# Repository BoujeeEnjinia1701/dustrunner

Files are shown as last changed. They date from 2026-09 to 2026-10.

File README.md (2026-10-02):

# DustRunner

     

**Area:** CleanTech · **TRL:** 3 of 9 (proof of concept on paper) · **Value-engineering target:** about $500 USD (estimated parts cost $573) · **Difficulty:** 4 of 5

Rail-free crawler robot that uses a rotating microfiber brush to dry-clean panel rows, clamps onto panel edges and docks to recharge.

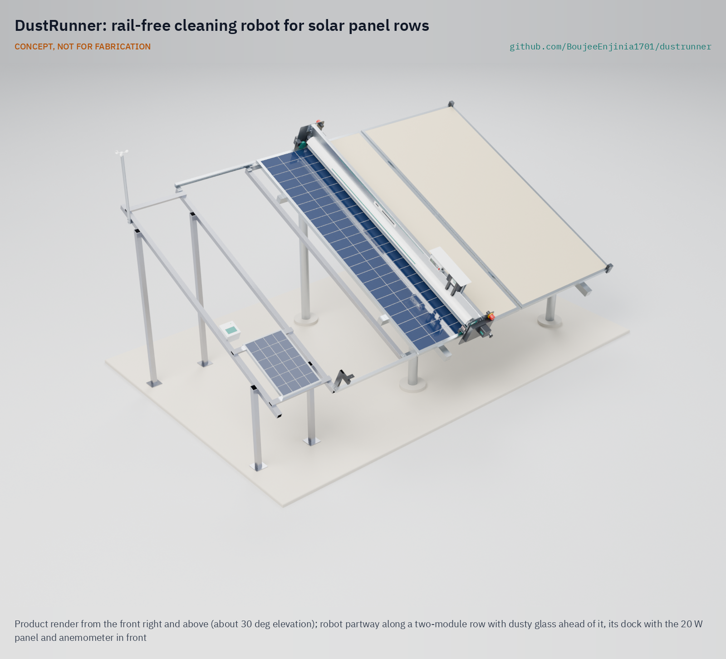
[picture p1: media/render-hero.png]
DustRunner: rail-free cleaning robot for solar panel rows, product render


[Exploded render](media/render-exploded.png) · [Detail render](media/render-detail.png) · [Interactive 3D model](media/viewer.html) · [Concept blueprint (PDF)](media/concept-blueprint.pdf) · [General arrangement DRN-DWG-001 (PDF)](cad/drawings/DRN-DWG-001.pdf) · [Sizing calculations](docs/04-calcs/01-sizing.md) · [Prototype build plan](docs/05-build-plan.md) · [Design decisions](docs/06-design-decisions.md) · [Review note](docs/REVIEW.md)

## Concept rationale

Soiling is a daily, gradual loss, so the answer is a small cleaning every day rather than a large one every month. Utility plants already do this with water-free robots bought as a service, but those machines are sized, priced and sold for rows hundreds of meters long. DustRunner scales the same idea down to one row of a small array: a full-width brush that rides on the module frames, so it needs no rails, never loads the glass and cannot fall between modules, and a dock that recharges it from a 20 W panel so it needs no wiring to the array.

The design is open and garage-buildable because the owners who need it most, farms with solar pumps, mini-grids and schools in dry regions, are far from robot vendors and service contracts. Aluminum tube, hobby gearmotors, a LiFePO4 pack and a microfiber sleeve can be bought, cut and repaired locally, and an open design can be adapted to other module lengths and table formats.

## Burning platform

Soiling cost at least 3 to 4 % of the world's solar electricity production in 2018, worth about 3 to 5 billion euros of lost revenue, with 4 to 7 % projected for 2023 as capacity grows fastest in dusty, sunny regions ([Ilse et al., Joule, 2019](https://www.cell.com/joule/fulltext/S2542-4351(19)30422-2)). The loss is steep where the sun is strongest: a 2026 study for Arar, Saudi Arabia, assumed monthly soiling losses of about 4 % in winter rising to 15 % in June and July ([Alharbi, *Energies*, 2026](https://www.mdpi.com/1996-1073/19/18/4373)).

Washing is the usual fix, and it spends water in the places that have least of it. Because each manual wash costs labor, the cost-optimal manual interval in the same study came out at about 60 days, and longer at low tariffs ([Alharbi, 2026](https://www.mdpi.com/1996-1073/19/18/4373)), so the array runs dirty for most of that time. A cheap daily dry pass changes that trade-off.

## Where it could be used

### By industry

| Industry | Use |
| --- | --- |
| Agriculture | Solar irrigation pumping arrays on farms, cleaned daily without trucking in water |
| Rural electrification | Mini-grid and community solar arrays at remote sites visited weekly or less |
| Commercial and light industrial | Ground-mounted arrays of 10 to 200 kW at warehouses, factories and depots |
| Education and health | School and clinic solar systems where no one is paid to clean panels |
| Water and telecoms utilities | Small arrays powering pumping stations, treatment plants and remote masts |
| Research and training | University test arrays and technical colleges comparing cleaning regimes |

### By country or region

| Country or region | Why it matters there |
| --- | --- |
| Saudi Arabia and the Gulf | Desert dust and scarce fresh water; a 2026 study for Arar assumed monthly soiling losses rising to 15 % in June and July ([Alharbi, 2026](https://www.mdpi.com/1996-1073/19/18/4373)) |
| Sahel and West Africa (for example Niger, Mali) | Harmattan dust from the Sahara can cut the output of decentralized solar and mini-grids by more than 50 % in the dry season, and Bamako needed about 21 cleanings a year to keep losses below 1 % ([Isaacs et al., *Applied Energy*, 2023](https://www.sciencedirect.com/science/article/abs/pii/S0306261923003574)) |
| India (Rajasthan, Gujarat) | More than 295,000 off-grid solar water pumps had been installed under the PM-KUSUM scheme by January 2024, about 59,700 of them in Rajasthan ([Press Information Bureau, 2024](https://www.pib.gov.in/PressReleaseIframePage.aspx?PRID=2004183&reg=3&lang=2)) |
| Chile (Atacama) | The Atacama has the highest long-term solar irradiance measured anywhere on Earth, with clouds present less than 5 % of the time in places, so arrays there are rarely washed by rain ([Molina, Falvey and Rondanelli, *Scientific Reports*, 2017](https://www.nature.com/articles/s41598-017-13761-x)) |
| Australia (inland) | A high-income market where ten deserts cover nearly 20 % of the country, the second driest continent ([Geoscience Australia](https://www.ga.gov.au/scientific-topics/national-location-information/landforms/deserts)) |

## What sparked the idea

The idea traces back to NASA's InSight lander on Mars, whose mission ended in December 2022 after dust gradually covered its solar panels and its batteries ran out of energy. With no cleaning mechanism on board, the team improvised: on windy days they sprinkled soil from the arm's scoop onto the panels so the falling grains would sweep some dust away and win back a little power ([NASA, "NASA Retires InSight Mars Lander Mission After Years of Science", 2022](https://www.nasa.gov/missions/insight/nasa-retires-insight-mars-lander-mission-after-years-of-science/)). The lesson carries back to Earth's deserts: a solar array without water depends on some dry, regular way of moving dust off the glass, and a small array needs one that costs no more than the energy it saves.

## Problem

Soiling cuts output of PV arrays in dusty regions by up to 15 to 25% a month in the dusty season, and water for washing is scarce.

## Concept

Rail-free crawler robot that uses a rotating microfiber brush to dry-clean panel rows, clamps onto panel edges and docks to recharge.

The robot spans one table from its lower to its upper module edge. End trucks ride on the module frames and hook under the frame lips, so no rails are needed along the row. A 2.2 m microfiber brush sweeps the glass dry once a day in the evening, and the robot parks off the glass in a clamp-on dock where a 20 W panel recharges its 12.8 V LiFePO4 pack and an anemometer checks the wind before each run. The TRL 3 calculations (DRN-CAL-001), run on the constructable design, give for a 40 m, 20 kWp row about 7.4 minutes and 7.7 Wh per cycle, a 15.9 kg robot and $573 in parts for robot, dock and anemometer, with a payback of about 3.2 years on rows of 60 m and 3 years from about 64 m. Six of fifteen requirements are met on paper, four are at risk (chiefly traction in wind, and the 60 m payback, which is over 3 years) and one falls short: the bearings, housings and fittings that make the design buildable put the parts USD 73 over the $500 value-engineering target. Amish restated the mass limit as 16.5 kg on 2026-10-02, with the wheel-load limits unchanged; the cost savings worth trying are in the design decisions register. Runs start only when the dock anemometer reads below 6 m/s and abort at 8 m/s (DRN-DDR-002). These are calculations, not test results.

Full design precis: [docs/02-concept.md](docs/02-concept.md)

## Key components

- Microfiber brush, 120 mm x 2.2 m, with brush motor and hood
- End trucks with belt-linked wheels and two drive gearmotors
- Edge-guide and hook rollers (the rail-free "clamp")
- 12.8 V 10 Ah LiFePO4 pack
- Controller (ESP32 class) and IR edge sensors
- Clamp-on dock with a 20 W PV panel, charger and anemometer; clamp-on end stops

The priced bill of materials is in [bom/bom.csv](bom/bom.csv); the parametric model is [cad/src/model.py](cad/src/model.py), with STEP files in `cad/step/`.

## Building the prototype

The [prototype build plan](docs/05-build-plan.md) shows, in pictures drawn from the model, how to make each of the 19 workshop-made components and fit them with the bought parts in 15 steps: the robot first, then the dock at the start of the row and the end stops at its far end. Making the design buildable added bearings, drive housings, roller brackets, dock brackets and clamps and a latch solenoid, recorded in [DRN-DDR-003](docs/decisions/0003-design-for-construction.md); they put the robot at about 15.9 kg and the parts at about $573. The work is sawing, drilling, tapping and folding aluminium, a little turning, and wiring bought modules at 12.8 V. Open decisions and the value-engineering notes are in the [design decisions register](docs/06-design-decisions.md).

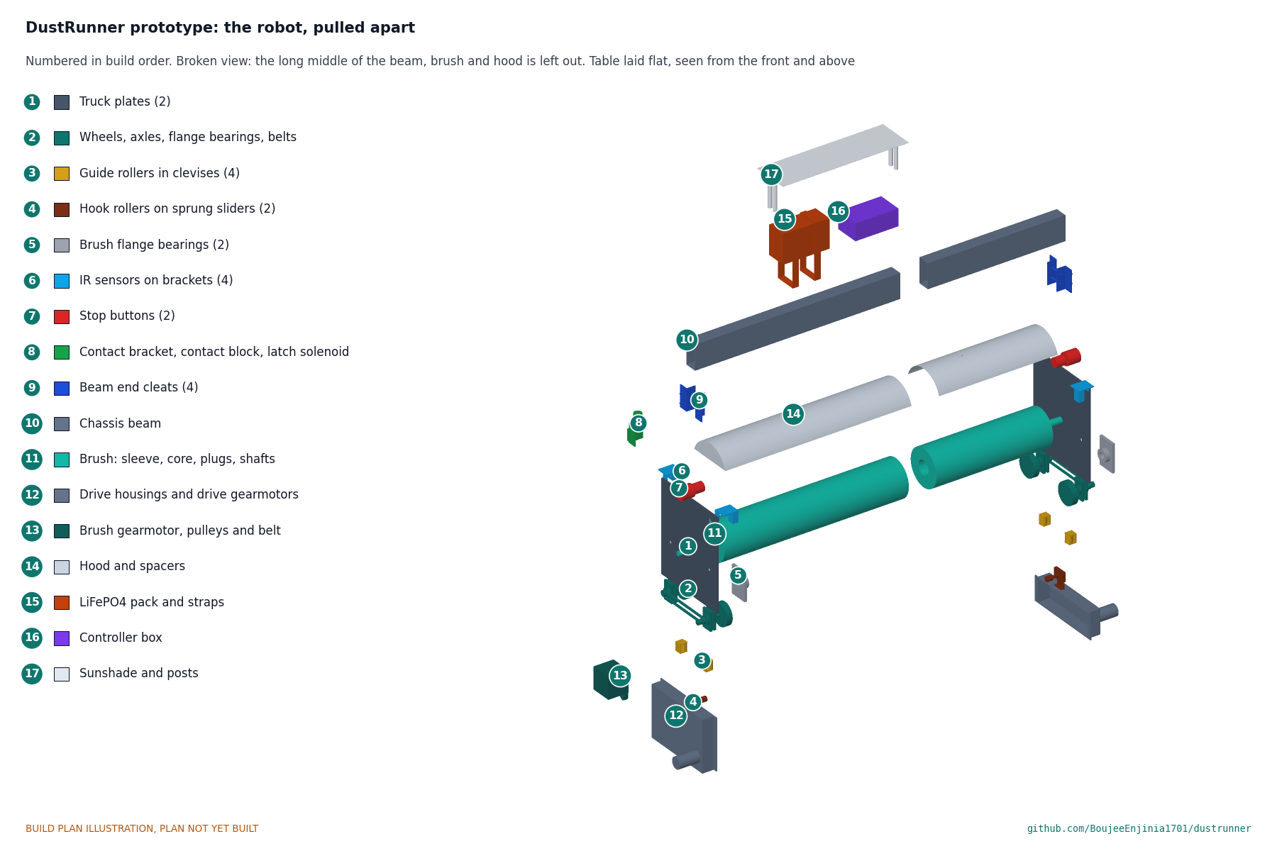
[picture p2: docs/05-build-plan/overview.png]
DustRunner robot, every component pulled apart and numbered in build order


## Safety

DustRunner is moving machinery with an unattended rotating brush and a lithium iron phosphate pack, and it works on live PV arrays at several hundred volts DC. The build plan's safety stops (Section 6) and the design precis's safety section apply to every build.

## Repository layout

| Folder | Contents |
| --- | --- |
| `docs/` | Problem, concept, requirements, calculations and design decisions |
| `cad/src/` | build123d Python source, the source of truth for all geometry |
| `cad/step/`, `cad/stl/` | Exported models for FreeCAD, other CAD tools and printing |
| `cad/drawings/` | 2D sketches and dimensioned drawings |
| `bom/` | Bill of materials |
| `electronics/` | KiCad schematics and PCB layouts |
| `firmware/` | Microcontroller code |
| `media/` | Renders, perspectives and photos |
| `build-log/` | Dated prototyping notes |

## Documentation

Controlled documents follow the portfolio [documentation standard](.kit/STANDARDS.md). Each carries a document ID (DRN-PRC-001 for the precis), a version and a revision history. Branded PDFs are built with `python .kit/render.py` and attached to GitHub Releases when a document is tagged, for example `DRN-PRC-001/v1.0`.

## Credits

Designed by Amish Chadha. See [CONTRIBUTORS.md](CONTRIBUTORS.md) for roles. To cite this design, use [CITATION.cff](CITATION.cff) (GitHub shows it as "Cite this repository").

AI assistance (Claude) was used to accelerate concept renders, prototype documentation and first-pass sizing calculations. Design direction and all decisions are Amish Chadha's, recorded in this repository's decision records (`docs/decisions/`).

## Licenses

- **Hardware** (CAD, drawings, BOM, electronics): [CERN-OHL-S v2](LICENSE)
- **Software** (firmware, scripts, notebooks): [MIT](LICENSE-SOFTWARE)

A project of the [Design Molecule](https://designmolecule.com) lab.

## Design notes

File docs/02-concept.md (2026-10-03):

---
doc_id: DRN-PRC-001
title: DustRunner design precis
project: DustRunner
doc_type: Design precis
version: "0.8"
status: Draft
date: '2026-10-02'
author: Amish Chadha
license: CERN-OHL-S-2.0
revisions:
- version: "0.1"
  date: '2026-09-24'
  author: Amish Chadha
  change: Initial scaffold
- version: "0.2"
  date: '2026-09-25'
  author: Amish Chadha
  change: Populate to TRL 2 (architecture, first-order numbers, traction, wind, economics, safety, media)
- version: "0.3"
  date: '2026-09-25'
  author: Amish Chadha
  change: TRL 3 update. Design choices decided per DRN-DDR-001; numbers replaced by DRN-CAL-001 (50 mm brush core, 70 N hook preload, 0.8 mm hood, dock anemometer); model, drawing DRN-DWG-001 and media refreshed
- version: "0.4"
  date: '2026-09-25'
  author: Amish Chadha
  change: Recommendations accepted by Amish (DDR-002). Start wind limit 6 m/s with abort at 8 m/s; row-entry wheel load accepted up to 75 N; budget kept at $500; numbers from DRN-CAL-001 v0.2
- version: "0.5"
  date: '2026-09-30'
  author: Amish Chadha
  change: Design made constructable (DRN-DDR-003); components and numbers from DRN-CAL-001 v0.3; build plan DRN-BLD-001 and design decisions register DRN-DEC-001 linked
- version: "0.6"
  date: '2026-10-01'
  author: Amish Chadha
  change: Budget treated as a value-engineering target
- version: "0.7"
  date: '2026-10-02'
  author: Amish Chadha
  change: 'Decisions of 2026-10-02 (DRN-DEC-001 v0.3): R10 met on paper at the restated 16.5 kg, R14 at risk, first candidate pilot site'
- version: "0.8"
  date: '2026-10-02'
  author: Amish Chadha
  change: 'Follow-ups carried out: calculation script re-run with the decided R10 and R14 status; numbers unchanged'
---

# DustRunner design precis

## Summary

DustRunner is a rail-free crawler robot that spans one PV table from its lower to its upper module edge, rides along the module frames on two end trucks that hook under the frame lips, and sweeps the glass dry with a 2.2 m rotating microfiber brush. It parks off the glass in a clamp-on dock at the start of the row, where a 20 W panel recharges its 12.8 V LiFePO4 pack and a cup anemometer tells it whether the wind allows a run. The TRL 3 calculations (DRN-CAL-001 v0.3), run on the constructable design of DRN-DDR-003, give for the 40 m, 20 kWp reference row about 7.4 minutes and 7.7 Wh per out-and-back cycle, a robot of about 15.9 kg and $573 in parts for robot, dock and anemometer. The bearings, housings, brackets and fittings that make the design buildable added about 2.1 kg and $73, so three requirements are now not met: the 15 kg mass limit of R10 (every wheel load still meets R10), the $500 budget of R13, and R14, with a payback of 3.2 years on a 60 m row (met from 63.5 m). Five are met and three are at risk: 5 mm frame steps (R4), traction in wind along the row (R9) and pack temperature (R11). A run starts only below 6 m/s at the dock anemometer and aborts above 8 m/s (DRN-DDR-002). How to resolve R10, R13 and R14 is open for Amish in the design decisions register ([06-design-decisions.md](06-design-decisions.md)); how to build the prototype is in the build plan ([05-build-plan.md](05-build-plan.md)).

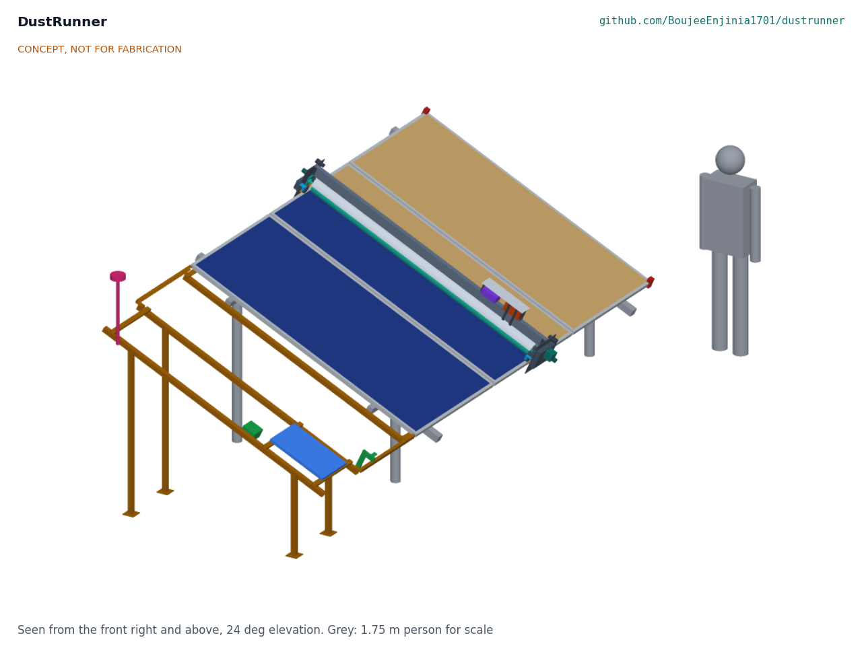
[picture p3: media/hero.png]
Hero render


*Figure 1. DustRunner partway along a three-module section of the reference table, moving away from its dock (brown, left, with the anemometer mast) toward the end stops (red). Glass behind the robot is clean; tan shows dust still to be removed. Grey figure: 1.75 m person for scale.*

## How it works

1. **Park and charge.** Between cycles the robot sits in the dock, a short pair of rails that continue the module frame profile past the end of the row. Parking off the glass means the robot never shades the array. A 20 W panel in the dock charges the pack through spring contacts; a third contact carries the anemometer signal.
2. **Start.** Once a day, in the evening after the array's output has dropped and before dew forms (DRN-DDR-001, D2), the controller checks pack charge, air humidity and the wind at the dock anemometer, sounds a short warning, then drives out of the dock. It starts only if the wind is below 6 m/s (DRN-DDR-002, N1).
3. **Travel.** Two end trucks carry the robot along the row. Each truck has two 70 mm polyurethane wheels on the top flange of the module frame, two guide rollers against the outer face of the frame and a hook roller under the frame's bottom flange, pushed up by a spring to 60 N. The trucks are the "clamp": they cannot lift off or slide down the slope, yet need no rail. A gearmotor with an encoder on each truck drives both of that truck's wheels through a toothed belt, and the controller keeps the two ends in step.
4. **Clean.** A 120 mm microfiber brush on a 50 mm aluminum core spans the slope and turns at about 150 rpm, pressed 4.5 mm into the glass plane at its bearings. A helical pattern on the brush conveys the loosened dust down the slope and off the lower edge. A hood over the brush limits dust thrown back onto clean glass.
5. **Stop and return.** IR sensors on each truck see the frame end; a clamp-on end stop at the far end is the mechanical backstop. The robot reverses the brush and cleans on the way back, then docks and latches. If the wind reported by the dock rises above 8 m/s during a run, the robot stops the brush and returns to the dock at once.

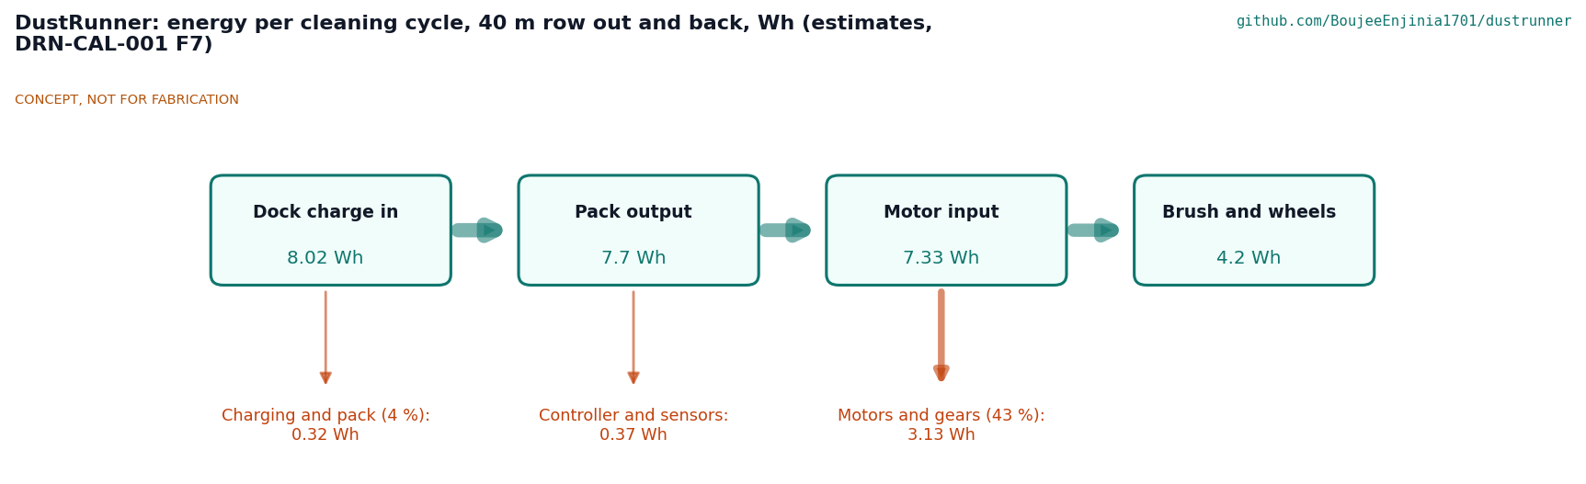
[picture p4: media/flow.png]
Energy flow


*Figure 2. Energy for one out-and-back cycle on the 40 m reference row, in Wh (DRN-CAL-001, F7). All values are estimates.*

## Main components

Numbers match the exploded view (Figure 3) and `bom/bom.csv`. Geometry is in `cad/src/model.py` and drawing DRN-DWG-001.

*Table 1. Main components.*

| # | Component | Choice | Notes |
| --- | --- | --- | --- |
| 1 | Chassis beam | 40 x 80 x 2 mm 6063 aluminum tube, 2,334 mm, bolted to each truck plate by two angle cleats | Cut to the module length for other tables |
| 2 | Microfiber brush | 120 mm diameter, 2,198 mm brushed length, on a 50 x 2 mm aluminum core | The 50 mm core keeps the interference at 3.4 to 4.4 mm along the brush |
| 3 | Brush hood | 0.8 mm aluminum sheet, 77 mm radius, with end guards and a sunshade over the pack | Also the finger guard at the brush ends |
| 4 | Brush motor and belt drive | 12 V DC gearmotor, about 60 W, toothed belt | Reversible; about 150 rpm at the brush; about 47 W in use |
| 5 | End trucks and wheels | 5 mm aluminum plates, 260 x 296 mm; two 70 x 18 mm polyurethane wheels each at 180 mm wheelbase on axles in flange bearings, belt-linked inside a drive housing that carries the motors | Wheels run on the frame top flange only |
| 6 | Drive gearmotors | Two 12 V 37 mm gearmotors with encoders, one per truck | Synchronized in firmware |
| 7 | Guide and hook rollers | 22 mm guide rollers in clevises on the frame face; 16 mm hook rollers on sprung sliders under the frame bottom flange, 60 N preload per truck | Keep the robot on the table in wind |
| 8 | Battery | LiFePO4, 12.8 V, 10 Ah (128 Wh) with BMS and temperature cut-offs | Under the sunshade |
| 9 | Controller | ESP32-class board, two drive channels, brush driver, current sensing, humidity and temperature sensor, IP65 box | Firmware is a sketch until TRL 4 |
| 10 | IR edge sensors | Four downward-looking reflective sensors, two per truck | Row-end and gap detection |
| 11 | Dock frame | Aluminum C-section rails continuing the module frame profile on brackets above three cross members, which stay clear of the hook roller path; two clamps to the first module's frame flange; ties; four legs | Clamp-on; no drilling |
| 12 | Dock PV panel | 20 W, about 530 x 350 mm, in the table plane | Charges the parked robot |
| 13 | Dock charger and contacts | LiFePO4 charge controller, three spring contacts on a post, latch tab; on the robot a contact block and a 12 V solenoid whose 6 mm pin drops into the tab | |
| 14 | End stops | Pair of three-piece clamps round the last module's frame edge, held by a clamp screw, with rubber buffers; low enough for the IR sensors to pass over | Mechanical backstop; the wheels meet the buffers |
| 16 | Dock anemometer | Cup anemometer with pulse output on a vertical mast clamped to the dock | Read before each start (DRN-DDR-001, D3) |

Item 15 (wiring, fuse, switches, stop buttons and fasteners) has no callout.

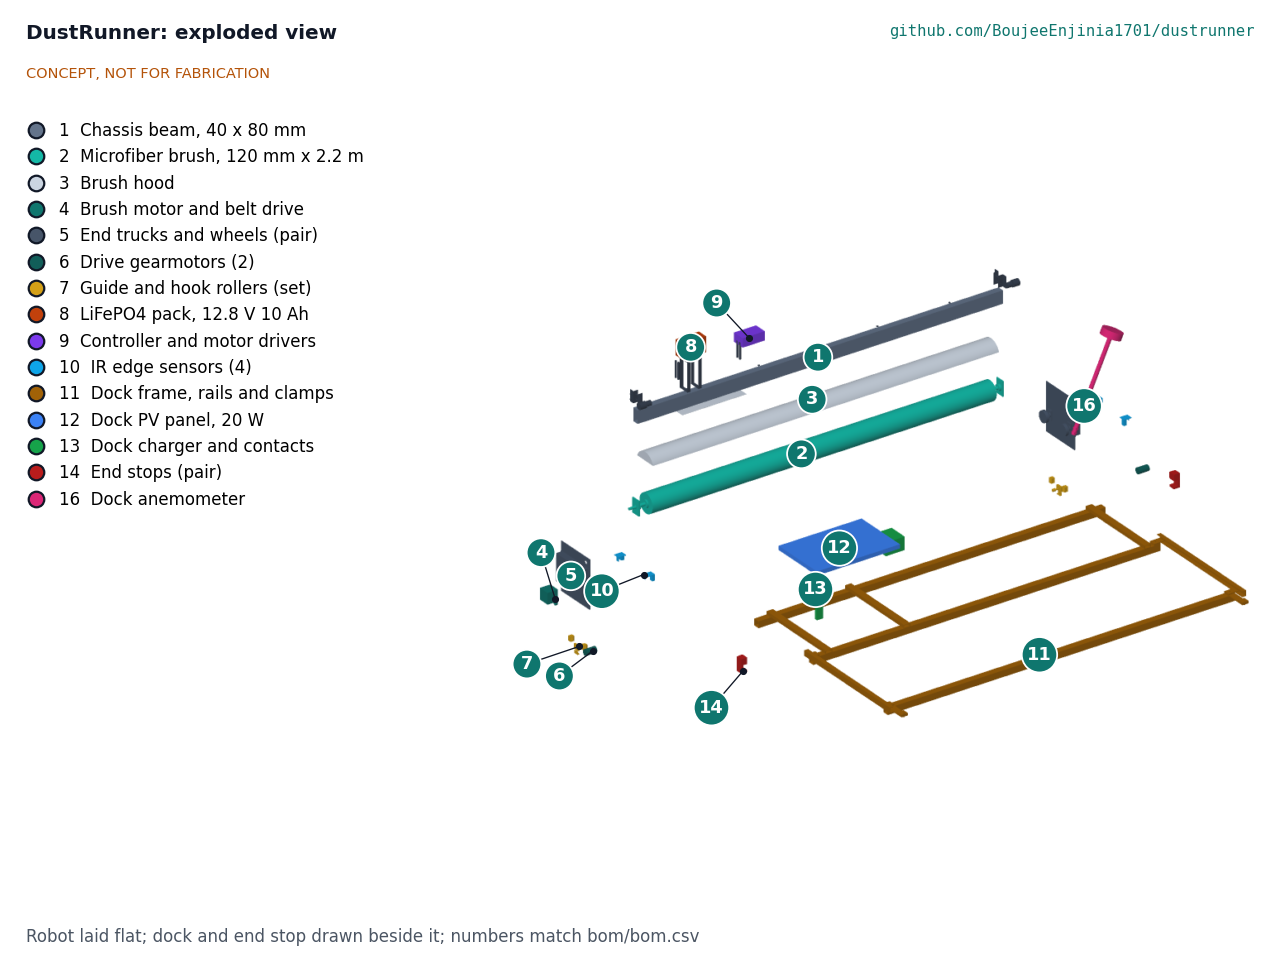
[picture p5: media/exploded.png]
Exploded view


*Figure 3. Exploded view with numbered callouts matching the BOM. The robot is laid flat in the table plane; the dock and end stops are drawn beside it. Upper-end twins of paired parts are shown without numbers.*

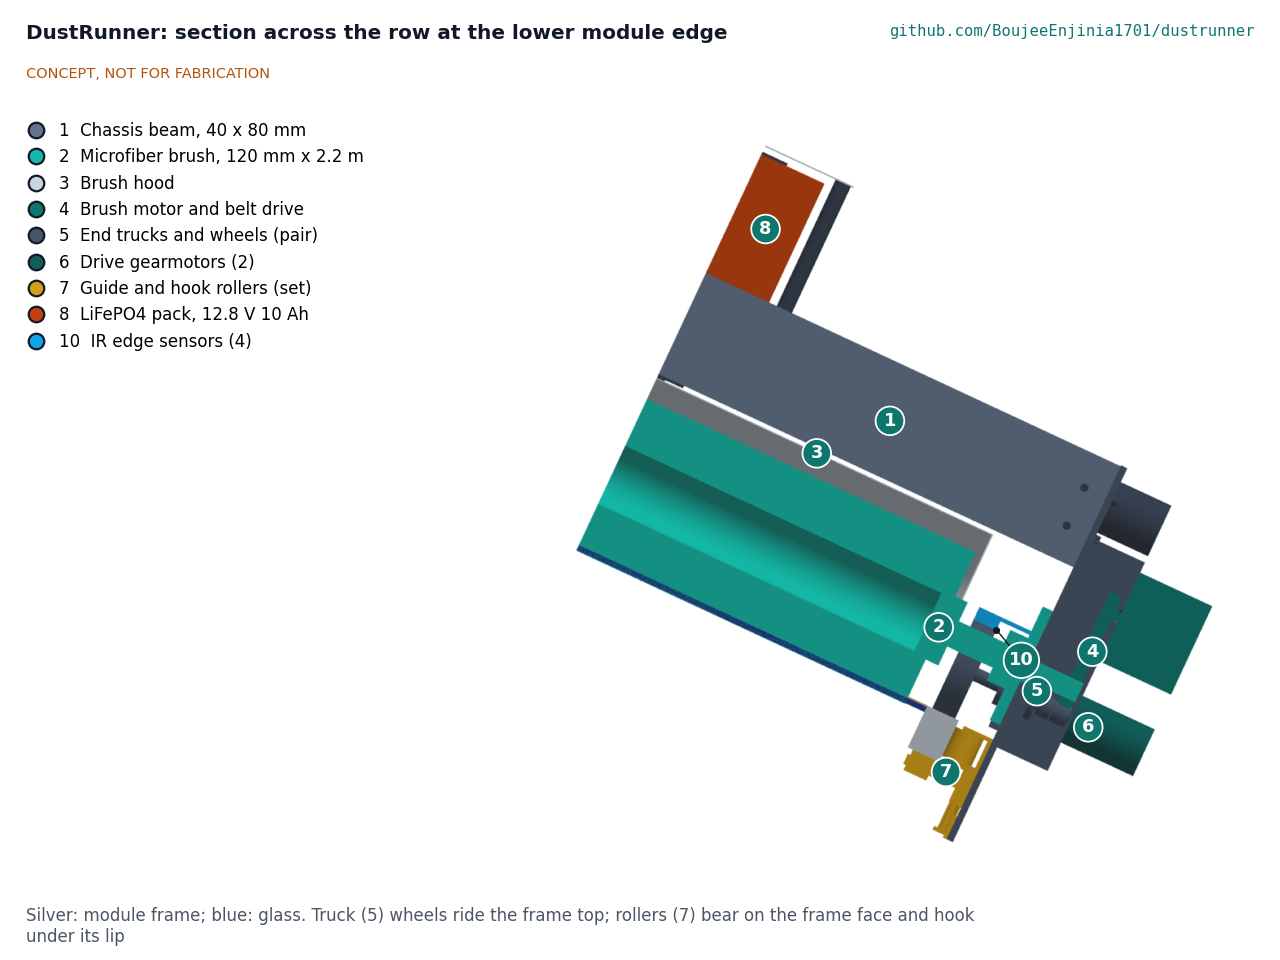
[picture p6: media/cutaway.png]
Cutaway


*Figure 4. Section across the row through the robot at the lower module edge, showing how the end truck wraps the frame.*

## Numbers at TRL 3

All values are from DRN-CAL-001 v0.2, which prints each from `docs/04-calcs/sizing.py`. They are first-principles estimates; the assumptions behind them (pile pressure, friction coefficients, frame flange width) are listed there and must be measured.

*Table 2. Key numbers.*

| Quantity | Value | Requirement |
| --- | --- | --- |
| Robot mass | 15.9 kg, including about 2.1 kg added for construction | R10 met on paper (16.5 kg, restated 2026-10-02); weighed at TRL 4 |
| Brush contact | About 67 N on the glass, 30 N drag, 28 W mechanical (13 to 50 W over the assumed ranges) | |
| Electrical power while cleaning | 67 W (brush 47 W, drives 17 W, electronics 3 W) | |
| Wheel load | 55 N brushing at 25°; 58 N at worst tilt; about 72 N for about a second at row entry | R10 met (75 N allowed for the transient, DRN-DDR-002) |
| Traction margin, friction 0.4 | 1.79 in still air; 1.30 at the 6 m/s start limit; 1.07 at the 8 m/s abort limit (0.98 and 0.81 at friction 0.3) | R9 at risk |
| 5 mm frame step | About 9 N extra push needed, about 14 N spare | R4 at risk |
| Parked at 35 m/s | 555 N along the row on a latch rated about 2.8 kN; 137 N net lift on the hook rollers | R9 parked case met |
| 40 m row, out and back | 7.4 min; 7.6 Wh from the pack | |
| 100 m row, out and back | 17.4 min; 19.6 Wh from the dock | R7 met |
| Autonomy | Three 100 m cycles and three days of standby use 67 of 102 Wh; 9 days with no sun on the 40 m row | R8 met |
| Dock harvest | 45 Wh/day at 3 sun hours; 82 Wh/day at 5.5 | R8 met |
| Coverage | 98.4 % of the glass on the 40 m row | R5 met |
| Stopping | Brush 0.13 s, robot 0.06 s after power is cut | R12 met |
| Parts cost | $573.00 (16 lines) | Over the value-engineering target by USD 73 (R13, target $500) |
| Payback, mid case | 3.2 years on a 60 m row (3 years from 63.5 m); 1.9 years on 100 m; 4.7 years on the 40 m reference row | R14 at risk (kept, not restated; 2026-10-02) |

The pack is cycled lightly (under 10 % of capacity a day on the reference row), which is kind to LiFePO4 cells in heat. The beam is not critical: with its load and a 250 N point load at mid-span it is stressed to about 17 MPa and deflects about 2.9 mm. Water saved is about 122 to 350 L per avoided wash of the reference row, about 1.5 to 4.2 m³ a year for monthly washing.

## Key design choices

Amish decided the design choices below on 2026-09-25 by approving the TRL 2 recommendations (DRN-DDR-001). Amish then accepted the recommendations raised by the TRL 3 calculations (DRN-DDR-002); they are listed after the first set.

- **One robot per row, spanning the full slope** (D1). A full-width robot needs no steering on the glass and cannot fall between modules. The concept is limited to tables whose short edges are free of clamps, as stated in R4.
- **Ride on the frame edges, not on the glass** (D1, D10). Wheels on the frame keep weight off the glass and coating. The first supported format is 1P portrait tables of 2,278 mm modules.
- **Rail-free, with a short dock and clamp-on end stops** (D11). The dock and stops are the only added hardware and clamp on without drilling. The mechanical end stops stay as the independent backstop to the IR sensors.
- **Dry microfiber brush, no water and no airflow** (D12). Airflow is added only if tests show that dust is re-deposited.
- **Charging at the dock from a 20 W panel** (D4), not from a panel on the robot.
- **Both wheels driven on each truck, with preloaded hook rollers** (D5). DRN-CAL-001 sets the preload by a 60 N wheel-load rule: 60 N per truck for the constructable design.
- **Evening cleaning, gated by the humidity sensor** (D2). While on the glass the robot shades a strip along one module for a few seconds, which costs 1 to 2 kWh a year.
- **Anemometer at the dock** (D3), read through the dock contacts before each start.
- **LiFePO4 at 12.8 V, 10 Ah** (D6). A SwapCell pack is not used: at about 468 Wh and 48 V it is far larger than DustRunner needs.
- **Reference row and payback target** (D7, D8). The 40 m reference row is kept; R14 applies to rows of 60 m or more.
- **Budget** (D9). `budget_usd` stays at $500 for robot, dock and anemometer as a hypothetical value-engineering target, not a limit. The priced BOM of the constructable design is $573, USD 73 over the target; savings worth trying are in DRN-DEC-001.
- **Start and abort wind limits** (DRN-DDR-002, N1). A run starts only below 6 m/s at the dock anemometer and aborts above 8 m/s. This is a firmware rule; it lifts the traction margin at the start of a run from 1.07 to 1.30 at friction 0.4 and will be revisited once friction is measured.
- **Row-entry wheel load** (DRN-DDR-002, N2). R10 allows up to 75 N per wheel for the second or so as the lead wheels enter the first module, subject to the module maker's frame guidance; no landing strip is added.
- **No cost contingency yet** (DRN-DDR-002, N3). `budget_usd` stays at $500 as the value-engineering target and the estimate stays indicative until quotes exist. Getting quotes is purchasing, which is TRL 4 work and on hold.

## Safety

> **Safety:** DustRunner is moving machinery with a rotating brush, a lithium iron phosphate battery, and it works on an energized PV array that can carry several hundred volts DC, on hot glass, up to about 1.6 m above the ground.

- **Rotating brush and pinch points.** The brush, belts and wheels can catch fingers, hair and clothing. The hood covers the brush ends; each truck has an emergency stop button; the brush stops when a truck lifts off the frame. The brush coasts to rest in about 0.13 s once power is cut (DRN-CAL-001, H1). Nobody should reach under the hood while the robot is powered.
- **Unexpected start.** The robot runs on a timer with nobody present. It must carry a clear warning label, start only after a short audible warning, and have a lockout switch at the dock.
- **Falling robot.** A 15.9 kg robot leaving the row end could injure someone below. Two independent stops (IR sensing and the mechanical end stop) and the hook rollers address this (R9). The end stop and dock latch hold with factors above 4 on paper, but traction in wind is marginal, so runs start only below 6 m/s and abort above 8 m/s (DRN-DDR-002; DRN-CAL-001, C4, C13, D1 to D4).
- **PV array electrical hazard.** Strings carry DC voltages that can be lethal and cannot be switched off in daylight. Nothing on the robot may touch cables, connectors or junction boxes; installation and maintenance follow the array owner's electrical safety rules. Damaged module glass exposes live parts.
- **Battery.** LiFePO4 is less prone to thermal runaway than other lithium-ion chemistries but can still vent and burn if crushed, shorted or overcharged. Use a pack with a BMS, fuse the pack output, block charging below 0 °C and above about 45 °C, and keep the pack shaded and ventilated (R11 is at risk on pack temperature).
- **Hot surfaces.** Module glass and frames can reach about 75 °C. Wear gloves when installing or servicing in daylight.
- **Module warranty.** Abrasive cleaning, or a cleaning tool the maker has not cleared, can void the module warranty. Check the maker's cleaning guidance and ask the maker to clear the robot before use (see DRN-PRB-001).

## Open questions

- [ ] Brush pile pressure, drag power and cleaning effectiveness on real dust, dry and after dew (R2).
- [ ] Long-term abrasion of anti-reflective coatings by daily microfiber contact (R3).
- [ ] Friction coefficient of polyurethane on dusty frames (R9); the traction margin in wind depends on it.
- [ ] Visible frame flange width of target modules; the wheel tread needs about 21 mm (R4).
- [ ] Pack temperature when parked in the sun, and the charging window it allows (R11).
- [ ] Module makers' positions on frame loading, including the 72 N row-entry transient, and on robotic dry cleaning (R10).
- [ ] How dust conveyed off the lower edge builds up at the lower frame lip over time.
- [ ] Pilot site and co-design partner (DRN-DDR-001, O1). Decided 2026-10-02: a university or national lab outdoor PV test site in a dusty climate; first candidate to approach Arizona State University's Photovoltaic Reliability Laboratory in Mesa.

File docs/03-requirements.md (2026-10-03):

---
doc_id: DRN-REQ-001
title: DustRunner requirements
project: DustRunner
doc_type: Requirements
version: "0.8"
status: Draft
date: '2026-10-02'
author: Amish Chadha
license: CERN-OHL-S-2.0
revisions:
- version: "0.1"
  date: '2026-09-24'
  author: Amish Chadha
  change: Initial scaffold
- version: "0.2"
  date: '2026-09-25'
  author: Amish Chadha
  change: First measurable requirements for TRL 2, with a reference row and status against the concept
- version: "0.3"
  date: '2026-09-25'
  author: Amish Chadha
  change: Apply DRN-DDR-001 (R14 restated for rows of 60 m or more; R13 covers the anemometer; reference row and table format kept); status from DRN-CAL-001
- version: "0.4"
  date: '2026-09-25'
  author: Amish Chadha
  change: Recommendations accepted by Amish (DDR-002). R9 restated with a 6 m/s start limit and 8 m/s abort limit; R10 allows 75 N for the row-entry transient; status from DRN-CAL-001 v0.2
- version: "0.5"
  date: '2026-09-30'
  author: Amish Chadha
  change: Status from DRN-CAL-001 v0.3 for the constructable design (DRN-DDR-003); R10 (mass), R13 and R14 not met. No target changed
- version: "0.6"
  date: '2026-10-01'
  author: Amish Chadha
  change: Budget treated as a value-engineering target
- version: "0.7"
  date: '2026-10-02'
  author: Amish Chadha
  change: R10 mass limit restated as 16.5 kg (wheel loads unchanged) and R14 kept and marked at risk, as decided by Amish on 2026-10-02
- version: "0.8"
  date: '2026-10-02'
  author: Amish Chadha
  change: 'Status from DRN-CAL-001 v0.6 (script re-run; printed counts agree with the decided counts); no target changed'
---

# DustRunner requirements

These requirements are checked by calculation in DRN-CAL-001 v0.6, for the constructable design of DRN-DDR-003. On paper, six are met, four are at risk, one falls short of its target and four cannot be verified at TRL 3. The parts added to make the design buildable moved R10, R13 and R14 off their targets; on 2026-10-02 Amish decided to restate R10's mass limit as 16.5 kg, keeping the wheel-load limits (the robot weighs 15.9 kg and is weighed at TRL 4), and to keep R14 and treat it as at risk until quotes (3.2 years on a 60 m row; met from 63.5 m). R13 falls short (estimated parts cost $573, USD 73 over the value-engineering target of $500); the cost savings worth trying are in the value engineering section of the design decisions register (DRN-DEC-001). The others at risk are R4 (5 mm frame steps and frame flange width), R9 (traction in wind along the row, margin 1.30 at the 6 m/s start limit but 0.98 if friction is only 0.3) and R11 (pack temperature while charging in the sun). R2, R3, R6 and R15 need tests or trials. Targets are still proposals for review, not validated with users or a pilot site, except where DRN-DDR-001 or DRN-DDR-002 records Amish's decision.

The **reference row** used throughout, kept by DRN-DDR-001 (D7), is one fixed-tilt table, one module high in portrait (1P), with 35 modules of 2,278 x 1,134 mm and about 580 W each: about 40 m long, about 90 m² of glass and about 20 kWp, tilted 25°, with the lower glass edge about 0.6 m above the ground. The first supported table format is 1P portrait with 2,278 mm modules (DRN-DDR-001, D10).

*Table 1. Requirements and status at TRL 3.*

| ID | Requirement | Target | Status (DRN-CAL-001) | Verification (TRL 3 or later) |
| --- | --- | --- | --- | --- |
| R1 | Water-free cleaning | No water or liquid used in normal operation | Met by design | Design review |
| R2 | Cleaning effectiveness on dry dust | Daily dry pass keeps the average soiling loss at 1.5 % or less when the site soiling rate is 0.3 to 0.5 % per day | **Not verifiable at TRL 3**; depends on dust type and dew. R14 on the 60 m row would need a residual below 1.3 % | Later soiling-station comparison |
| R3 | Glass and coating safety | Only microfiber touches the glass; brush interference 3 to 5 mm along the whole brush; no hard bristles, grit traps or metal within 10 mm of the glass; complies with the module maker's cleaning guidance | **Not verifiable at TRL 3**; geometry met (3.5 to 4.4 mm with a 50 mm core; nothing else within 10 mm); abrasion over years unknown | Maker guidance review; later abrasion test on sample glass |
| R4 | Fit the reference table | 1P portrait modules 2,278 mm long with 30 to 35 mm frames; short (top and bottom) edges free of clamps; tilt 10 to 35°; gaps between modules up to 25 mm; frame height steps up to 5 mm | **At risk**: 25 mm gaps pass; a 5 mm step needs about 9 N against about 12 N spare traction; the wheel tread needs a visible frame flange of about 21 mm or more | Survey of target tables and frame profiles |
| R5 | Coverage | 95 % or more of the glass area brushed per pass | Met: 98.4 % on the 40 m row | Model check |
| R6 | Rail-free installation | No rails along the row; only a dock at one end and clamp-on end stops at the other; no drilling of modules or structure; installed by two people in 60 min or less | **Not verifiable at TRL 3**; rail-free and clamp-on by design; time unverified | Installation trial |
| R7 | Cycle time | A 100 m row cleaned out and back in 20 min or less | Met: 17.4 min | Calculation |
| R8 | Energy autonomy | Three daily cycles on a 100 m row with no sun; recharged from the dock panel in one day at 3 peak sun hours | Met: 68 of 102 Wh usable; 45 Wh harvested against 23 Wh a day | Energy calculation |
| R9 | Stay on the row | Two independent means stop the robot at each row end; hook rollers keep it on the table in operating wind; a run starts only when the dock anemometer reads below 6 m/s and aborts to the dock above 8 m/s (DRN-DDR-002, N1); robot parked and latched in the dock survives 35 m/s | **At risk**: parked, latch and end stops hold with factors over 4; traction margin 1.30 at the 6 m/s start limit and 1.07 at the 8 m/s abort limit at friction 0.4, but 0.98 and 0.81 at friction 0.3 | Wind load calculation; later friction measurement |
| R10 | Load on the modules | Robot mass 16.5 kg or less (restated from 15 kg by Amish, 2026-10-02, DRN-DEC-001); each wheel load 60 N or less in steady running and 75 N or less for the brief transient as the lead wheels enter the first module (DRN-DDR-002, N2), subject to the module maker's frame loading guidance; carried on the frame only; no load on the glass except brush contact | **Met on paper**: 15.9 kg with the parts added for construction, to be weighed at TRL 4. Wheel loads met: 59 N per wheel brushing at worst tilt with 60 N hook preload; about 73 N for about a second at row entry | Mass estimate; module maker's guidance |
| R11 | Environment | Electronics IP65; operates at 0 to 50 °C ambient on glass up to 75 °C; UV-stable plastics; dust-sealed bearings | **At risk**: the parked pack may exceed its 45 °C charging limit in the sun; a sunshade is added | Datasheets and design review; later thermal check |
| R12 | Safe to be near | Emergency stop button on each end truck; brush and drives stop within 2 s of a stop command or of a truck lifting off the frame; brush ends guarded by the hood; nothing on the robot can reach PV cables, connectors or junction boxes | Met on paper: brush stops in 0.13 s, robot in 0.07 s; belt guards and a stop button in each truck plate | Design review; later bench test |
| R13 | Affordable | Robot, dock and anemometer for one row, parts at or below the value-engineering target of $500 (`budget_usd`, a hypothetical control target) | **Over the value-engineering target by USD 73**: $573.00 indicative after the parts added for construction (DRN-DDR-003); the target stays at $500 (DRN-DDR-002, N3); savings to try are in DRN-DEC-001 | Priced BOM (`bom/bom.csv`) |
| R14 | Pays for itself | Value of the recovered energy covers the parts cost in 3 years or less on rows of 60 m or more, mid case (0.3 % per day soiling, monthly manual wash as baseline, $0.10/kWh) | **At risk** (kept, not restated; Amish, 2026-10-02): 3.2 years on a 60 m row at $573, revisited when real quotes exist; met on rows of 63.5 m or more; 1.9 years on a 100 m row (4.7 years on the 40 m reference row, which is below the scope of R14) | Energy yield calculation |
| R15 | Serviceable | Microfiber sleeve replaced in 15 min or less without taking the robot off the row; motors, bearings, wheels and battery are standard catalog parts | **Not verifiable at TRL 3**; catalog parts by design | Later service trial |

## Assumptions

- Specific yield about 5.5 kWh per kWp per day for a clean array at a sunny desert site (estimate).
- Soiling rate 0.3 % per day (mid case) and 0.49 % per day (high case, as measured at QEERI in Qatar; see DRN-PRB-001).
- Baseline practice is a manual wash every 30 days. Longer manual intervals, or no cleaning at all, make DustRunner's case stronger.
- Electricity or displaced diesel valued at $0.10/kWh. Diesel-displacing mini-grids are often higher.
- 20 W dock panel, 75 % derating for heat, dust, wiring and a simple charge controller.
- Friction coefficients, brush pile pressure and the visible frame flange width are assumptions listed in DRN-CAL-001, Table 1, and must be measured.

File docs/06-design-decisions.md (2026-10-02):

---
doc_id: DRN-DEC-001
title: DustRunner design decisions register
project: DustRunner
doc_type: Design decisions register
version: "0.3"
status: Draft
date: '2026-10-02'
author: Amish Chadha
license: CERN-OHL-S-2.0
revisions:
  - version: "0.1"
    date: '2026-09-30'
    author: Amish Chadha
    change: Register opened with the build plan; open decisions from DRN-DDR-001 to 003 and the review note
  - version: "0.2"
    date: '2026-10-01'
    author: Amish Chadha
    change: Budget treated as a value-engineering target
  - version: "0.3"
    date: '2026-10-02'
    author: Amish Chadha
    change: Amish approved the recommendations for open items 1 to 7 on 2026-10-02 (DRN-DDR-003 accepted, R10 mass restated as 16.5 kg, R14 kept and at risk, robot-side latch solenoid, ASU Photovoltaic Reliability Laboratory as first candidate pilot, appearance items, re-render); moved to decisions made
---

# DustRunner design decisions register

Every design decision still to be made, and every decision made, in one place. Each decision is argued in full in its decision record under `docs/decisions/`; this register is the index Amish works from. The build plan (`docs/05-build-plan.md`, DRN-BLD-001) describes the design as it stands and does not list open decisions.

## Open decisions

None. All open decisions were decided on 2026-10-02.

## To confirm when parts are bought

| # | What to confirm | Why it matters | Source |
| --- | --- | --- | --- |
| 1 | The target modules' frame: top flange at least 21 mm wide (25 mm assumed), frame 33 mm deep, and room on top of the long-side bottom flange for the 6 mm clamp jaw | Wheel tread, hook roller, dock rail profile and frame clamp all depend on it | DRN-CAL-001 [C12]; DRN-DDR-003, P12 |
| 2 | The flange bearings' bolt spacing and height (10 mm and 20 mm bores) | They set the bearing bolt holes and the clearances to the sensor brackets (4 mm) and clevises | DRN-DDR-003, P3, P5 |
| 3 | The gearmotors' face hole patterns and shaft sizes | They set the housing holes and the 6 to 10 mm coupling | DRN-DDR-003, P4 |
| 4 | A compression spring giving 60 N at 20 mm, about 9 mm across | Sets the hook preload | DRN-CAL-001 [C0] |
| 5 | The solenoid's pull and stroke against the pin's return spring, at 12 V for about 1 s | The robot must lift its own latch pin | DRN-DDR-003, P9 |
| 6 | The charge controller's LiFePO4 profile (14.4 V) and the pack BMS's 0 °C and 45 °C charge cut-offs | Battery safety (R11) | DRN-PRC-001, Safety |
| 7 | The module maker's cleaning and frame-load guidance (60 N steady, 75 N at row entry) | R3 and R10 | DRN-DDR-002, N2 |
| 8 | The real masses of the bought parts | The 15.9 kg estimate and the preload rule | DRN-CAL-001 [A2], [A4] |

## Value engineering

Value-engineering target: USD 500 (a hypothetical control target, not a limit). Estimated cost of the constructable design: USD 573 (USD 73 over the target). Main cost drivers and savings worth trying:

- The USD 73 over the target is the parts added to make the design buildable (DRN-DDR-003): flange bearings, drive housings, couplings, roller clevises and sliders, dock brackets, clamps, ties and foot plates, the latch solenoid and beam cleats. The largest single lines are the LiFePO4 pack (USD 45), the beam (USD 30) and the dock panel (USD 22).
- Savings worth trying at quotes: cheaper flange bearings, a lighter dock, and 4 mm or pocketed truck plates (which also save about 1 kg; R10's mass limit was restated as 16.5 kg on 2026-10-02, so this is now a saving, not a fix).
- Every price is indicative; quotes are TRL 4 work and on hold (DRN-DDR-002, N3).

## Decisions made

| Date | Decision | Decided by | Record |
| --- | --- | --- | --- |
| 2026-09-25 | TRL 2 review items D1 to D12: full-width robot on 1P frames, evening cleaning gated by humidity, dock anemometer, 20 W dock charging, both wheels driven with preloaded hook rollers, 12.8 V LiFePO4 pack, 40 m reference row, R14 restated for rows of 60 m or more, budget $500, 1P portrait 2,278 mm modules first, mechanical end stops kept, dry microfiber without airflow | Amish: "proceed with all of your recommendations across all batches. Make sure we don't proceed to TRL 4 on any of them." | DRN-DDR-001 |
| 2026-09-25 | Start a run only below 6 m/s and abort at 8 m/s (N1); R10 allows 75 N per wheel for the row-entry transient (N2); keep `budget_usd` at $500 as the value-engineering target and look at contingency on quotes (N3) | Amish: "i accept all your recommendations, go with them across all repos." | DRN-DDR-002 |
| 2026-09-26 | DustRunner chosen for the first batch of product renders | Amish | `docs/REVIEW.md`, session 2026-09-26 |
| 2026-09-30 | Write the illustrated build plan and make the design physically buildable while drawing it; keep open decisions out of the build plan, in this register | Amish: "If you are realising that the design cannot be built as per concept - fix the design assumptions to match and be physically feasible as you draw the illustrations." The changes made under this instruction were accepted on 2026-10-02 (below). | DRN-DDR-003; DRN-BLD-001 |
| 2026-10-02 | Design for construction accepted: the changes P1 to P16 that make the design buildable (guide roller clevises and 28 mm plate gap, sprung hook sliders, flange bearings, drive housings, beam cleats, latch solenoid, dock rail brackets, frame clamps, vertical legs and mast, three-piece end stops), as drawn | Amish: "i approve your recommendations for all 555 open decisions." | DRN-DDR-003, P1 to P16 |
| 2026-10-02 | Robot mass: option (c), R10's mass limit restated as 16.5 kg now, with the 60 N and 75 N wheel-load limits unchanged; the robot is weighed at TRL 4 | Amish: "i approve your recommendations for all 555 open decisions." | DRN-DDR-003, A2; DRN-CAL-001 [A3], [A4] |
| 2026-10-02 | Payback: option (b), R14 kept at 3 years on rows of 60 m or more and marked at risk rather than restated; revisited when real quotes exist | Amish: "i approve your recommendations for all 555 open decisions." | DRN-DDR-003, A3; DRN-CAL-001 [I4], [I9] |
| 2026-10-02 | Latch release: option (a), the robot-side 12 V solenoid lifts its own pin, as drawn | Amish: "i approve your recommendations for all 555 open decisions." | DRN-DDR-003, A4 |
| 2026-10-02 | Pilot site and co-design partner: a university or national lab outdoor PV test site in a dusty climate; first candidate to approach Arizona State University's Photovoltaic Reliability Laboratory in Mesa | Amish: "i approve your recommendations for all 555 open decisions." | DRN-DDR-001 and 002, O1 |
| 2026-10-02 | Product appearance model deviations 1 to 6 accepted for renders, except that the dock contact bracket and bearing flanges (item 5) are taken from the constructable design, not as appearance-only parts | Amish: "i approve your recommendations for all 555 open decisions." | `docs/REVIEW.md`, session 2026-09-26 |
| 2026-10-02 | Renders: option (a), update `cad/src/product_model.py` to the constructable design and re-render the photoreal renders, card and social preview on Amish's Mac | Amish: "i approve your recommendations for all 555 open decisions." | DRN-DDR-003, Consequences |

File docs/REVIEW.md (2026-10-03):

# Review note: DustRunner

## Session 2026-09-25: /populate to a strong TRL 2 (overnight batch run)

### What was done

- `docs/01-problem.md` (DRN-PRB-001 v0.2): problem with cited soiling and water figures, users and operating context, prior work (Ecoppia, NOMADD, SolarCleano, an academic prototype) with links, constraints including module warranty and live-array hazards, out of scope, open questions. There was no co-design checklist to keep.
- `docs/03-requirements.md` (DRN-REQ-001 v0.2): 15 measurable requirements (R1 to R15) against a defined 40 m, 20 kWp reference row, with a status column and assumptions.
- `docs/02-concept.md` (DRN-PRC-001 v0.2): how it works, numbered components, mass, power and energy per cycle, autonomy, traction, wind, recovered energy and payback, cost, design choices, safety, open questions.
- `cad/src/concept_media.py`: massing model of a three-module section of the reference table (frames, glass, dust film, purlins, posts), the robot (beam, brush, hood, motors, end trucks, rollers, battery, controller, sensors), the clamp-on dock with its 20 W panel, and the end stops. Every robot and dock part carries a BOM number.
- `media/`: hero with a 1.75 m person, blueprint sheet (PNG, PDF, SVG), `model.glb` and `viewer.html`, exploded view with callouts 1 to 14, cutaway (section across the row at the lower module edge) and an energy flow diagram per cleaning cycle with estimated values. The exploded view and cutaway are rendered by the script with the kit's renderer so the robot is readable at a useful scale; temporary `_views` folders are removed.
- `bom/bom.csv`: 15 lines with indicative prices, numbered to match the exploded view; `bom/bom-notes.md` updated.
- `README.md`: hero image, links line, concept paragraph and key components updated.
- `docs/pdf/`: branded PDFs of the three controlled documents.

### Key results (estimates, to be checked at TRL 3)

| Quantity | Estimate | Requirement |
| --- | --- | --- |
| Robot mass | about 12 kg; about 52 N per wheel on the frames with hook preload | R10 met on paper |
| Power while cleaning | about 70 W (brush 50 W, drives 16 W, electronics 3 W) | |
| 40 m row, out and back | about 7 min, about 8 Wh from the dock | |
| 100 m row, out and back | about 17 min, about 20 Wh | R7 met |
| Autonomy | about 102 Wh usable; about 5 days on a 100 m row with no sun | R8 met |
| Dock panel harvest | about 82 Wh/day at 5.5 sun hours, 45 Wh/day at 3 | R8 met |
| Coverage | about 98 % of the glass across the slope | R5 met |
| Traction | about 83 N available against about 39 N needed (both wheels driven, 50 N hook preload per truck, friction 0.4 assumed) | Margin about 2, unverified |
| Wind while cleaning | stop above 8 m/s; parked at 35 m/s about 650 N along the row and 170 N net lift | R9 unverified |
| Recovered energy, mid case | about 1,220 kWh a year, about $120 a year | |
| Payback | about 4.0 years mid case; about 2.0 years at 0.49 %/day; about 1.6 years on a 100 m row | **R14 not met** in the mid case |
| Parts cost | about $485 for robot and dock | R13 met, about 3 % margin |

Requirements not met or not shown:

- **R14 (payback within 3 years) not met** in the mid case on the 40 m reference row: about 4 years.
- **R2 (cleaning effectiveness) not shown:** the 1.5 % residual loss with daily dry cleaning is an assumption; dew-cemented dust may not come off dry.
- **R3 (glass and coating safety) not shown:** long-term abrasion from daily microfiber contact is unknown, and some module makers require approval of motorized cleaning tools.
- **R9 (wind) unverified:** the operating wind limit needs a wind input that is not in the BOM.
- **R13 margin is thin:** an anemometer would bring the cost to about $500.

### Proposed, awaiting Amish

Status update: items 1 to 8 and 10 were decided by Amish, 2026-09-25: go with recommendation (DRN-DDR-001, D1 to D12). Item 9 has no recommendation and stays proposed, awaiting Amish.

1. **Scope: one full-width robot per row, riding on the frames of 1P portrait tables.** Options: (a) as proposed; (b) a smaller robot that moves on the glass; (c) add a transfer cart between rows. Recommendation: (a). This limits fit to tables whose short module edges are free of clamps.
2. **Cleaning time.** Options: night (as Ecoppia does), evening before dew forms, or dawn. Recommendation: evening, gated by the humidity sensor.
3. **Wind input.** Options: (a) anemometer at the dock (about $15, cost about $500); (b) a weather feed over the network; (c) a fixed wind rule from motor current. Recommendation: (a).
4. **Charging at the dock rather than a panel on the robot.** Recommendation: dock panel, 20 W.
5. **Traction: both wheels driven on each truck and spring-preloaded hook rollers.** Recommendation: yes, pending friction measurement.
6. **12.8 V LiFePO4, 10 Ah.** A SwapCell pack is not proposed because DustRunner needs about a quarter of its energy at a quarter of its voltage. Recommendation: LiFePO4.
7. **Reference row for requirements and payback.** 40 m and 20 kWp is proposed. A 100 m reference would meet R14; that choice changes how the pitch is judged, so it is Amish's.
8. **R14 target.** Options: keep 3 years and accept that the reference row does not meet it; relax it to 5 years; or restate it per row length. Recommendation: restate it as "3 years or less on rows of 60 m or more".
9. **Pilot site and partner** (solar pumping farm, mini-grid operator or university test array).
10. **Budget.** Parts cost is within `budget_usd` ($500); no change proposed. `project.yaml` is unchanged, including `pitch` and `problem`: the "15 to 25 %" figure matches arrays left a month or more in the dusty season (QEERI about 13 % a month, Arar 11 to 18 % a month in summer), and DRN-PRB-001 now states that context. A more precise wording ("up to 15 to 25 % a month in the dusty season") is suggested for Amish to consider.

### Safety concerns

- Rotating brush, belts and wheels on an unattended machine that starts on a timer: guards, emergency stops on both trucks, an audible start warning and a lockout at the dock.
- A 12 kg robot falling from up to 1.6 m if it leaves the row end or is lifted by wind: two independent end stops and hook rollers; wind loads unverified.
- Live PV strings at several hundred volts DC that cannot be switched off in daylight: the robot must never touch cables, connectors or junction boxes; damaged glass exposes live parts.
- LiFePO4 pack: BMS, fused output, no charging below 0 °C, shaded and ventilated.
- Hot glass and frames up to about 75 °C during installation and service.
- Module warranty risk from abrasive cleaning or cleaning tools the maker has not cleared.

### Problems and notes

- The kit's default scale figure stands in front of the table's lower edge, where it hid the robot's lower end and the dock, so the script places the 1.75 m person itself as a context part standing on the ground beyond the far end of the row.
- The legacy `cad/src/model.py` placeholder is untouched (TRL 3 work).
- Suggestion, not done: a soiling-station measurement at the pilot site before any build would answer R2 and R14 at low cost.

### Recommended next step

Review this note and the media, then decide items 1, 3, 7 and 8. If approved, run `/advance-trl3` to check the brush power, traction, wind and frame-load estimates by calculation and produce the parametric model and drawing sheet.

## Session 2026-09-25: TRL 3

Amish approved all TRL 2 recommendations on 2026-09-25 ("proceed with all of your recommendations across all batches. Make sure we don't proceed to TRL 4 on any of them."). This session advanced DustRunner to TRL 3 and stopped there.

### What was done

- `docs/decisions/0001-trl2-review-decisions.md` (DRN-DDR-001 v0.1): decisions D1 to D12 recorded as "Decided by Amish, 2026-09-25: go with recommendation"; O1 (pilot partner) left open.
- `docs/01-problem.md`, `docs/02-concept.md`, `docs/03-requirements.md` revised to v0.3: problem line reworded, design choices no longer "proposed", R14 restated for rows of 60 m or more, R13 now covers the anemometer, every number replaced by DRN-CAL-001 values.
- `docs/04-calcs/01-sizing.md` (DRN-CAL-001 v0.1) and `docs/04-calcs/sizing.py`: mass, brush contact and core deflection, wheel loads, traction, frame steps, wind, beam, energy, coverage, stopping, cost and payback, with a status for every requirement. The script imports the model and reads the BOM and budget.
- `cad/src/model.py`: parametric build123d model (robot, dock, end stops, reference module) exporting `cad/step/dustrunner-{robot,dock,end-stop,assembly}.step` and `cad/stl/dustrunner-{robot,dock,end-stop}.stl`.
- `cad/src/sheets.py` and `cad/drawings/DRN-DWG-001.{svg,pdf,png}`: general arrangement at Rev P1 (top and front views at 1:20, section A-A at 1:5, isometric, interface notes), marked "CONCEPT, NOT FOR FABRICATION" and "PRELIMINARY, NOT FOR FABRICATION". The concept sheet stays DRN-DWG-010, so DWG-001 was free.
- `bom/bom.csv`: 16 lines, all priced with a supplier type; item 16 (dock anemometer) added. `bom/bom-notes.md` updated.
- `cad/src/concept_media.py` now builds the robot, dock and end stops from `model.py`; all media re-rendered and checked (hero, blueprint, exploded with callout 16, cutaway, flow, GLB and viewer). No `_views` folders remain.
- `project.yaml`: `trl: 3`, `trl_target: 3`, `trl_evidence` lists the docs, DDR, CAL note and script, model, STEP files, drawing and BOM; problem line reworded. `README.md` matches.

### Requirements at TRL 3 (DRN-CAL-001, Table 8)

Six met, five at risk, none not met, four not verifiable at TRL 3.

| Status | Requirements |
| --- | --- |
| Not met | None |
| At risk | R4 (5 mm frame step: 9 N needed, 14 N spare; tread needs a frame flange of about 21 mm or more); R9 (traction margin 1.10 in an 8 m/s wind along the row at friction 0.4, 0.82 at friction 0.3); R10 (13.8 kg and 58 N per wheel brushing, but about 72 N for about a second at row entry); R11 (pack may exceed its 45 °C charge limit in the sun); R13 ($500.00 against $500, no margin) |
| Not verifiable at TRL 3 | R2 (cleaning effectiveness), R3 (abrasion; the geometry is met), R6 (installation time), R15 (sleeve change time) |
| Met | R1, R5 (98.4 %), R7 (17.4 min), R8 (67 of 102 Wh), R12 (0.13 s), R14 (2.8 years on a 60 m row) |

Key numbers: robot 13.8 kg; 67 W while cleaning; 7.4 min and 7.6 Wh per cycle on the 40 m row; 17.4 min on a 100 m row; parked at 35 m/s, 555 N along the row and 137 N net lift, held with factors over 4; payback 4.1 years on the 40 m row, 2.8 years on 60 m, 3.5 years on 60 m if sleeves are replaced every year.

Changes forced by the calculations: the brush core grows from 40 to 50 mm (a 40 mm core lets the interference fall to 2.8 mm mid-span, outside R3); hook preload set at 70 N per truck (highest value keeping brushing wheel loads at 60 N or less); hood thinned to 0.8 mm; a sunshade added over the pack. Mass rose from about 12 kg to 13.8 kg.

### Decisions recorded

D1 to D12 in DRN-DDR-001: full-width robot on 1P frames; evening cleaning gated by humidity; anemometer at the dock; 20 W dock charging; both wheels driven with preloaded hook rollers; 12.8 V LiFePO4, no SwapCell; 40 m reference row kept; R14 restated for rows of 60 m or more; budget kept at $500 with the problem line reworded; 1P portrait 2,278 mm modules first; mechanical end stops kept; dry microfiber without airflow. The SwapCell interface v0.3 items do not apply because DustRunner uses its own pack.

### Proposed, awaiting Amish

1. **Pilot site and co-design partner (O1).** No recommendation; to be picked per area later. Still proposed, awaiting Amish.
2. **Start wind limit (new, from C4 and C7).** Options: (a) keep 8 m/s and accept a traction margin of about 1.1; (b) start a run only below 6 m/s at the dock anemometer and keep 8 m/s as the abort limit; (c) raise the hook preload, which breaks the 60 N wheel-load target. Recommendation: (b), revisited once friction is measured. This changes the R9 target, so it is Amish's. **Decided by Amish, 2026-09-25: go with recommendation** (DRN-DDR-002, N1).
3. **Row-entry wheel load (new, from C2).** Options: (a) restate R10 to allow about 75 N for the brief row-entry transient, subject to the module maker's frame guidance; (b) add a glass-height landing strip at the dock end so the brush is loaded on entry (small cost, over budget); (c) lower the preload to about 55 N and accept less traction. Recommendation: (a). **Decided by Amish, 2026-09-25: go with recommendation** (DRN-DDR-002, N2).
4. **Cost contingency (new, from I1).** The BOM uses the whole $500. Options: keep $500 and treat R13 as at risk until quotes exist; or raise `budget_usd` to about $550 to hold a 10 % contingency. Recommendation: keep $500 for now; decide on quotes. `budget_usd` is unchanged. **Decided by Amish, 2026-09-25: go with recommendation** (DRN-DDR-002, N3).

### Safety concerns

- Unattended rotating brush, belts and wheels that start on a timer: guards, a stop button on each truck, an audible start warning and a lockout at the dock. Stopping time is well inside 2 s on paper.
- A 13.8 kg robot falling from up to 1.6 m: end stops and the dock latch hold with factors over 4, but traction in wind along the row is marginal; the start wind limit (item 2) matters for safety as well as function.
- Live PV strings at several hundred volts DC: nothing on the robot may touch cables, connectors or junction boxes; damaged glass exposes live parts.
- LiFePO4 pack parked in the sun: BMS with low- and high-temperature charge cut-offs, fused output, sunshade and ventilation (R11 at risk).
- Hot glass and frames up to about 75 °C; module warranty risk from cleaning tools the maker has not cleared.

### Other notes

- No existing TRL 4 material was found (the `build-log/` folder holds only its README and was not touched).
- The review note listed no unchecked citations, so none were re-verified in this session.
- Friction coefficients, brush pile pressure and the visible frame flange width are assumptions; they drive R4, R9 and the brush power.

### Recommended next step

Decide items 2 to 4 above and name a pilot partner when ready. **TRL 4 is on hold by Amish's instruction**, and no TRL 4 work was started. For reference only, TRL 4 would need: measured friction of polyurethane on dusty frames and measured brush pile pressure and drag; a survey of target module frame profiles; a lab test article of one end truck on a frame section, and of the brush on sample glass (effectiveness and abrasion); a pack temperature check in the dock; a test report (TST, `environment: lab`) and build log entries.

## Session 2026-09-25: recommendations accepted

Amish wrote on 2026-09-25: "i accept all your recommendations, go with them across all repos." Every open item with a recommendation is now "Decided by Amish, 2026-09-25: go with recommendation", recorded in `docs/decisions/0002-recommendations-accepted.md` (DRN-DDR-002 v0.1).

### Decisions applied and what changed

| # | Decision | Before | After |
| --- | --- | --- | --- |
| N1 | Start a run only below 6 m/s at the dock anemometer; abort at 8 m/s | Operate below 8 m/s; traction margin 1.10 at start (friction 0.4) | Start below 6 m/s: margin 1.33 at friction 0.4, 1.00 at 0.3 [C13]; abort at 8 m/s: 1.10 and 0.82. R9 still at risk |
| N2 | R10 allows about 75 N per wheel for the row-entry transient | 72 N against a 60 N limit: R10 at risk | 72 N against 75 N (transient), 58 N against 60 N (steady): R10 met |
| N3 | Keep `budget_usd` at $500; decide contingency on quotes | $500, BOM $500.00 | Unchanged: $500, BOM $500.00; R13 still at risk |

Files changed: DRN-REQ-001 v0.3 to v0.4 (R9 and R10 restated, R13 note); DRN-PRC-001 v0.3 to v0.4 (start and abort rule, design choices, key numbers); DRN-CAL-001 v0.1 to v0.2 and `sizing.py` (new [C13], restated R9 and R10 checks); DRN-DDR-002 v0.1 (new); `project.yaml` (DDR-002 added to `trl_evidence`; `budget_usd`, pitch and problem unchanged); `README.md` (status line and the new write-up sections). Geometry, BOM and prices are unchanged, so DRN-DWG-001 stays at Rev P1; the STEP, STL, drawing, media and PDFs were regenerated.

### Requirement status now (DRN-CAL-001 v0.2)

| Status | Requirements |
| --- | --- |
| Not met | None |
| At risk | R4 (5 mm frame step and flange width); R9 (traction margin 1.33 at the 6 m/s start limit, 1.00 at friction 0.3); R11 (pack charge temperature in the sun); R13 ($500.00 against $500) |
| Not verifiable at TRL 3 | R2, R3, R6, R15 |
| Met | R1, R5, R7, R8, R10, R12, R14 |

Counts: 7 met (was 6), 4 at risk (was 5), 0 not met, 4 not verifiable.

### Still awaiting Amish

- O1: pilot site and co-design partner (no recommendation was made).

### Cross-repo actions

None. DustRunner uses its own 12.8 V pack (DRN-DDR-001, D6) and no shared module.

### TRL 4

TRL 4 remains on hold by Amish's instruction. The parts of N1 and N3 that need TRL 4 work (measuring wheel friction on dusty frames, writing firmware beyond a sketch, requesting supplier quotes) are decided but on hold. `trl: 3` and `trl_target: 3` are unchanged.

## Session 2026-09-26: sources strengthened

- "By country or region" in `README.md`: five of six rows had no citation. Each row now carries a verified primary or peer-reviewed source, and the text was trimmed to what the source supports:
  - Sahel and West Africa: no source, now [Isaacs et al., *Applied Energy*, 2023](https://www.sciencedirect.com/science/article/abs/pii/S0306261923003574) (Harmattan soiling losses above 50 % for decentralized solar; about 21 cleanings a year in Bamako).
  - India (Rajasthan, Gujarat): no source, now [Press Information Bureau, 8 February 2024](https://www.pib.gov.in/PressReleaseIframePage.aspx?PRID=2004183&reg=3&lang=2) (PM-KUSUM off-grid solar pumps installed, national and Rajasthan figures).
  - Chile (Atacama): no source, now [Molina, Falvey and Rondanelli, *Scientific Reports*, 2017](https://www.nature.com/articles/s41598-017-13761-x) (highest long-term irradiance on Earth, very low cloud occurrence).
  - Australia (inland): no source, now [Geoscience Australia, deserts](https://www.ga.gov.au/scientific-topics/national-location-information/landforms/deserts); the unsupported claim about remote farms and service distances was removed.
  - US Southwest: removed, because no credible source was verified within this session's search allowance. Australia, Chile and Saudi Arabia remain as high-income examples.
- Arar figures (Alharbi, *Energies*, 2026): on checking the paper, the adopted monthly losses are about 4 % in winter rising to 15 % in June and July; 11 to 18 % is a literature range quoted for comparison. The README and DRN-PRB-001 (v0.4) now quote the adopted values, and the 60-day manual interval is stated as the base-case optimum, longer at low tariffs.
- Kept and verified: NASA InSight retirement release (What sparked the idea), Alharbi 2026. Ilse et al., *Joule*, 2019 is peer-reviewed and kept; it could not be re-fetched in this session.
- Not changed (outside this session's scope): DRN-PRB-001 still cites PV Tech (trade press) alone for the QEERI figures and Polywater (vendor) alone for water per module; both should get primary sources at the next revision.
- The "Qatar 11 to 18 %" wording in item 10 of the TRL 2 session above predates this correction.
- No budget change.

## Session 2026-09-26: product appearance model and photoreal renders

Amish chose this repo for the first batch of product renders on 2026-09-26.

### What was done

- `cad/src/product_model.py` (new): a product appearance model for photoreal renders. `product_parts()` returns every part with its colour, material, BOM line, group and exploded-view offset; `TITLE` and `RENDER_VIEWS` define three views: `hero` (robot partway along a two-module row with its dock and anemometer in front), `exploded` (robot, dock and end stops) and `detail` (the lower end truck clamped on a section of the module frame). It adds:
  - Robot: anodized beam with fillets, an accent stripe and a name plate; white powder-coated hood with rolled edges, hangers and an accent band; microfiber sleeve (fabric) on its core ends, stub shafts and bearing flanges; sunshade frame on four posts; strapped LiFePO4 pack with a label; IP65 controller box with a lid parting line, a clear side window showing the board, a shielded module and a lit status light, a main switch and cable glands.
  - End trucks: graphite plates with corner fillets, lightening holes, bolts and a badge; polyurethane tyres on metal hubs; wheel belt guards; drive gearmotors split into gearbox, can and encoder cap; guide rollers on clevis tabs; hook arms with rollers and preload springs; IR sensors with lenses; copper charge contacts; a red emergency stop on a yellow base on each truck (the two stop buttons of BOM item 15). The lower truck also carries the brush gearmotor housing (with cooling slots) and the brush belt cover.
  - Dock: C-section rails, cross members and posts, painted clamps with bolts, legs with feet, a framed 20 W panel with cells, a charger box with a lit charge light, spring contacts with the latch pin on a contact post, and a three-cup anemometer on its mast. End stops get rubber buffers and clamp bolts.
  - Context (not in the BOM): two reference modules (frames, backsheet, cells), a dust film ahead of the robot (illustrative), purlins, rafters, posts with concrete footings and a compact gravel ground patch.
- `README.md`: the hero image now points to `media/render-hero.png`, and the links line starts with the exploded render. The render files will be produced by the orchestrator.
- Self-check previews (matplotlib, clear parts left out) were reviewed for all three views; they are scratch files, not repo media.

### Differences from model.py (each Proposed, awaiting Amish)

1. Coordinates. model.py builds everything in local table coordinates (glass plane). The product model builds each part in those coordinates and then places it with the same tilt transform as `cad/src/concept_media.py` (Z up, ground at Z = 0), because the renderer needs a ground plane. Recommendation: accept; no dimension changes.
2. Scene layout. The robot is shown at u = 560 mm, partway along the first of two modules, not parked in the dock as in `assembly()`. Recommendation: accept, since it shows the brush on the glass and the dock together.
3. Exploded view. The dock is drawn 300 mm nearer the robot along the row and the end stops 900 mm nearer, so the exploded view stays compact; the dock legs are left out of it. Recommendation: accept (render layout only).
4. Groups. The lower end truck, the brush drive and a short section of the module frame are in the `internal` group so the `detail` view can frame the edge clamp; the upper truck, its mirror image, is in `shell`. Recommendation: accept.
5. Small appearance additions not in model.py: a bracket and foot that tie the dock contact block to the rail (model.py shows the block alone), the sunshade posts and cross bars that seat it on the beam, bearing flanges on the truck plates, hood hangers, pack straps, and rubber buffers on the end stops. These imply small hardware covered by BOM items 3, 11, 13, 14 and 15; no BOM line or cost changes. Recommendation: accept as appearance only, and confirm the dock contact bracket at the next design revision.
6. Materials and colours. Wheel tyres are shown in the kit accent (#0F766E) and the hood and sunshade in white powder coat; model.py sets no finishes. Recommendation: accept, or choose a different tyre colour.

### Status

This is an appearance model only: no tolerances, no fabrication detail, no change to PARAMS, the BOM, the calculations or the drawing. `trl` stays 3 and TRL 4 remains on hold.

## Session 2026-09-27: kit 1.5.0 and image quality

- Kit 1.5.0 synced: STANDARDS v1.5 (sections 12 to 15: product renders, storefront images and image quality, public release, authorship and signing), `.kit/cards.py`, `.kit/image_qc.py`, `.kit/release_gate.py`, issue templates, and the `/render-product` and `/release` commands. `CLAUDE.md` now matches `.kit/CLAUDE.md`.
- Every `media/render-*.png` recaptioned from its original render with the new layout: the title, concept label and repository sit in a band above the render and the view note in a band below it, each line wrapped to the image width, so no text overlaps other text or the render or runs off the image. `media/card.png` and `media/social-preview.png` regenerated with the same rules.
- `python .kit/image_qc.py` and `python .kit/release_gate.py` pass. trl stays 3.

## Session 2026-09-30: prototype build plan and design for construction (kit 1.7.0)

Kit 1.7.0 installed (`.kit/`, `.claude/commands/`, `CLAUDE.md`). Amish's instructions of 2026-09-30: write the illustrated build plan in the approved format, "fix the design assumptions to match and be physically feasible as you draw the illustrations", and keep outstanding decisions out of the build plan in a separate register.

### What was done

- `cad/src/model.py` rebuilt to a constructable level of detail: `build_components()` returns every robot, dock and end-stop part; `python cad/src/model.py --check` runs 123 constructability checks (contacts, clearances, robot on the module, parked in the dock and at the end stop, hook roller path); all 123 pass. STEP and STL re-exported.
- `docs/decisions/0003-design-for-construction.md` (DRN-DDR-003 v0.1, Draft): every change, its reason, the knock-on changes and four items proposed, awaiting Amish.
- `docs/05-build-plan.md` (DRN-BLD-001 v0.1): 19 made components, bought parts, wiring, 15 assembly steps, first checks, safety stops, tools.
- `docs/06-design-decisions.md` (DRN-DEC-001 v0.1): 8 open decisions (7 after the 2026-10-01 budget wording pass), 8 items to confirm when parts are bought, decisions made.
- `cad/src/build_plan_media.py`: overview pictures (robot and dock), making sketches `cad/drawings/DRN-DWG-101` to `119`, 11 joint close-ups, 15 step pictures and a wiring diagram in `docs/05-build-plan/`.
- `docs/04-calcs/sizing.py` and DRN-CAL-001 v0.3 re-run for the constructable design (new [A4], [C0], [I9]); DRN-REQ-001 v0.5 and DRN-PRC-001 v0.5 updated; `bom/bom.csv` and `bom/bom-notes.md` repriced; `cad/src/sheets.py` and DRN-DWG-001 Rev P3; concept media regenerated (`cad/src/concept_media.py`); `project.yaml` (`design_state: constructable`, new evidence); README links line, "Building the prototype" and a short "Safety" section.

### Design changes made for construction (DRN-DDR-003)

1. Truck plate gap 28 mm (was 22): each guide roller now turns on an M8 bolt in a folded clevis, 6 mm off the plate (it used to fill the gap and rub the plate).
2. Hook roller on an 8 mm axle cantilevered from a 10 mm slider that runs on shoulder bolts and is pushed up by a spring on a seat bracket (the concept had a rigid arm, no axle, no spring); plates 24 mm taller (296 mm).
3. Each wheel axle in two flange bearings, one each side of the plate (stub axles could not carry the outboard belt).
4. Folded drive housings on the outer faces guard the belts and carry the gearmotors (which floated); shaft couplings; wheel and brush belts in separate layers; lower brush shaft stepped to 15 mm outboard of the plate.
5. Turned core end plugs, stub shafts in the plugs, and a 20 mm flange bearing on each plate (shafts butted the core and passed through the plates with no bearing).
6. Beam bolted to each plate by two angle cleats (it butted, unfixed).
7. Hood hung on five 3 mm spacers; sunshade on four posts; pack strapped (all floated).
8. IR sensors and the robot contact block on folded brackets on the plate face (they butted the plate edge).
9. Dock latch made real: a 12 V spring-return solenoid on the robot drops its 6 mm pin through a latch tab on the dock.
10. Dock contact block on a post bolted to the rail-start cross member (it floated 89 mm above the frame).
11. Dock cross members moved 6 mm below the rails and 30 mm inside them, rails held by L brackets inside the channel with spacers and shims; the two posts that blocked the hook roller's path removed.
12. Frame clamps rebuilt as bar, jaw, spacer and one M8 bolt round the first module's bottom flange (they touched nothing).
13. Dock legs vertical, bolted beside the cross members, on foot plates; three ties added; vertical anemometer mast in U-bolt clamps (it leaned 25°).
14. End stops rebuilt as three screwed pieces with an M8 clamp screw, 40 mm tall so the IR sensors pass over and the wheels meet the buffer (a sensor used to hit the stop first).
15. Reference module long sides modelled as C sections (context only).

### Key results (DRN-CAL-001 v0.3)

- Robot 15.9 kg (was 13.8 kg; about 2.1 kg of construction parts). Hook preload 60 N per truck by the existing 60 N wheel-load rule (was 70 N); wheel loads 56 N brushing, 59 N worst tilt, 73 N at row entry; traction margin 1.30 at the 6 m/s start limit (0.98 at friction 0.3).
- Parts $573.00 (was $500.00), USD 73 over the $500 value-engineering target. Payback 3.2 years on a 60 m row; 3 years from 63.5 m.
- Requirements: 5 met, 3 at risk (R4, R9, R11), **3 short of target: R10 (mass; wheel loads met), R13 (over the value-engineering target by USD 73: $573 against $500), R14 (3.2 years on 60 m)**, 4 not verifiable at TRL 3.

### Proposed, awaiting Amish

See DRN-DEC-001, open items 1 to 7: accept DRN-DDR-003 (recommend accept); restate R10's mass limit to 16.5 kg and weigh at TRL 4; keep R14 at risk until quotes; robot-side latch solenoid; pilot partner (no recommendation); render deviations of 2026-09-26; update the appearance model and renders. The budget is no longer an open decision: `budget_usd` stays $500 as a value-engineering target, and the savings worth trying are in the register's Value engineering section (2026-10-01).

### Stale media

The design changed visibly, so `media/render-hero.png`, `media/render-exploded.png`, `media/render-detail.png`, `media/card.png`, `media/social-preview.png` and `cad/src/product_model.py` are stale (concept trucks, hook arms, dock legs, leaning mast). They are made on Amish's Mac and were not regenerated.

### Safety concerns

- The latch now depends on a solenoid on the robot; it fails latched (spring out), and the parked-wind check [D2] is unchanged.
- The drive housings fully enclose the wheel and brush belts (pinch points, R12); the stop buttons sit in the truck plates.
- The dock must be clamped to the module frame without drilling and kept clear of array cables and junction boxes (build plan S5).

### Recommended next step

Amish reviews DRN-DDR-003 and the register, and decides the budget, R10 and R14 items. TRL 4 stays on hold; the build plan is paper only.

## Session 2026-10-02: open decisions decided

Amish, 2026-10-02: "i approve your recommendations for all 555 open decisions." This approves the recommendation written for each open decision in the design decisions register (DRN-DEC-001 v0.2). trl stays 3; no build or test work was done, and the model, BOM quantities and prices, and pictures are unchanged.

### Decisions recorded

Seven decisions, all moved to Decisions made in DRN-DEC-001, dated 2026-10-02:

1. DRN-DDR-003 accepted: design-for-construction changes P1 to P16, as drawn.
2. Robot mass: option (c), R10's mass limit restated as 16.5 kg, the 60 N and 75 N wheel-load limits unchanged; the robot is weighed at TRL 4.
3. Payback: option (b), R14 kept at 3 years on 60 m rows and marked at risk; revisited when real quotes exist.
4. Latch release: option (a), the robot-side 12 V solenoid lifts its own pin.
5. Pilot site and co-design partner: a university or national lab outdoor PV test site in a dusty climate; Arizona State University's Photovoltaic Reliability Laboratory in Mesa is the first candidate to approach.
6. Appearance items 1 to 6 accepted for renders, except that the dock contact bracket and bearing flanges (item 5) come from the constructable design, not as appearance-only parts.
7. Renders: option (a), update the appearance model to the constructable design and re-render on Amish's Mac.

Requirement status after decisions 2 and 3: 6 met on paper (R10 now met at 15.9 kg against 16.5 kg), 4 at risk (R4, R9, R11 and R14), 1 short of target (R13, USD 73 over the value-engineering target), 4 not verifiable at TRL 3.

### Documents changed

- `docs/06-design-decisions.md` (DRN-DEC-001 v0.3): open decisions moved to Decisions made; the truck-plate saving and the 2026-09-30 row updated.
- `docs/decisions/0003-design-for-construction.md` (DRN-DDR-003 v0.3, status Draft): accepted, with A2 to A4 accepted as recommended and a consequence added.
- `docs/decisions/0001-trl2-review-decisions.md` (DRN-DDR-001 v0.2) and `docs/decisions/0002-recommendations-accepted.md` (DRN-DDR-002 v0.2): O1 recorded as decided.
- `docs/03-requirements.md` (DRN-REQ-001 v0.7): R10 restated to 16.5 kg (met on paper); R14 at risk; summary counts.
- `docs/04-calcs/01-sizing.md` (DRN-CAL-001 v0.5): requirement table status for R10 and R14, counts and summary; no number re-run.
- `docs/02-concept.md` (DRN-PRC-001 v0.7): key numbers status for R10 and R14; pilot site question answered.
- `docs/01-problem.md` (DRN-PRB-001 v0.5): pilot site question answered.
- `README.md`: requirement summary.

### Follow-up actions to carry approved decisions into the design

1. Decision 2 (calculations): change R10's mass limit to 16.5 kg in `docs/04-calcs/sizing.py` so that its status line [J0] prints the decided counts.
2. Decision 3 (calculations): print R14 as at risk in `sizing.py` [J0], and recheck payback when real quotes exist.
3. Decision 6 (model): build the dock contact bracket and the bearing flanges in `cad/src/product_model.py` from the constructable parts of `cad/src/model.py`, not as appearance-only parts.
4. Decision 7 (pictures): update `cad/src/product_model.py` to the constructable design (trucks, hook arms, dock legs, vertical mast) and re-render the photoreal renders, `media/card.png` and `media/social-preview.png` on Amish's Mac.

### Points found in the review

- The row length at which payback reaches 3 years is given three ways: 63.5 m (DRN-DDR-003 and R14), about 64 m (the register's former item 3 and the README) and 65 m (option a).
- R14 was marked "Not met" in the requirements while the recommendation was to treat it as at risk; aligned now that item 3 is decided.

## Approved follow-ups carried out (2026-10-02)

Amish approved all follow-up actions from the 2026-10-02 sign-off. trl stays 3; no build or test work was done. No decision changed the geometry or the BOM, so `cad/src/model.py`, STEP, STL, `bom/bom.csv` and all build plan and concept pictures are unchanged.

### Follow-ups

1. Decision 2 (calculations): done. `docs/04-calcs/sizing.py` tests R10 against 16.5 kg (restated 2026-10-02); R10 is met at 15.9 kg.
2. Decision 3 (calculations): done. `sizing.py` prints R14 as at risk (3.2 years on a 60 m row against the 3 years kept; met from 63.5 m); payback is to be rechecked when real quotes exist (TRL 4 work, not done here). The cost line [I1] now uses the value-engineering wording: "Value-engineering target: USD 500. Estimated cost of the constructable design: USD 573 (USD 73 over the target)". R13 prints as "Short of target". The printed counts [J0] now agree with the decided counts: 6 met, 4 at risk, 1 short of target, 4 not verifiable at TRL 3.
3. Decision 6 (model): done. The dock contact bracket, the dock contact post and block, the latch solenoid and tab, and the flange bearings (axle and brush) in `cad/src/product_model.py` are now model.py's own parts, not appearance-only parts.
4. Decision 7 (appearance model and pictures): done in part. `cad/src/product_model.py` now takes both end trucks (plates, drive housings, clevis-mounted guide rollers, sprung hook sliders, beam cleats, sensor brackets), the beam cleat holes, hood spacers, sunshade posts and pack straps, the dock (rails on brackets, cross members, clamps, ties, vertical legs on foot plates, panel on the ties, charger, contact post) and the vertical mast with its clamps and the three-piece end stops from the constructable model. Render scenes were exported to `/home/claude/renders/dustrunner` (hero, exploded, detail, and the jobs file). Not done: the photoreal renders, `media/card.png` and `media/social-preview.png`, which are made on Amish's Mac.

### Key results

- Cost: USD 573 against the USD 500 value-engineering target (USD 73 over); unchanged. Mass: robot 15.9 kg; unchanged. `budget_usd` is unchanged.
- Requirement status changes: none in the documents (the script now prints the decided status). 6 met, 4 at risk (R4, R9, R11, R14), 1 short of target (R13), 4 not verifiable at TRL 3.
- Appearance deviations from model.py: the truck plate has no lightening holes (they would clash with the bolts of the constructable truck), and the anemometer cups, panel cells and charger label are appearance detail. Recorded as accepted by decision 6 of 2026-10-02; nothing new is proposed.

### Documents changed

- `docs/04-calcs/01-sizing.md` (DRN-CAL-001 v0.6), `docs/03-requirements.md` (DRN-REQ-001 v0.8), `docs/02-concept.md` (DRN-PRC-001 v0.8), `docs/05-build-plan.md` (DRN-BLD-001 v0.3, Rev P4 reference), `docs/decisions/0003-design-for-construction.md` (DRN-DDR-003 v0.4).
- `cad/src/sheets.py` and `cad/drawings/DRN-DWG-001` at Rev P4 (no geometry change); `cad/src/product_model.py`; `docs/04-calcs/sizing.py`.
- PDFs re-rendered with `python3 .kit/render.py`.

### Cross-repo actions

None.

## 2026-10-02: photoreal renders redone on the constructable design

Rendered with Blender Cycles on Amish's Mac from the updated appearance model; captioned with `.kit/photo_caption.py`; `media/card.png` and `media/social-preview.png` regenerated with `.kit/cards.py`. Views: hero, exploded, detail. image_qc passes. Appearance deviations are those logged above as proposed, awaiting Amish.

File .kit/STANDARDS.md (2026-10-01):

---
doc_id: OHP-STD-001
title: Documentation and drawing standard
project: Open Hardware Portfolio
doc_type: Standard
version: "1.7"
status: Released
date: 2026-09-30
author: Amish Chadha
license: CC-BY-SA-4.0
revisions:
  - version: "1.0"
    date: 2026-09-24
    author: Amish Chadha
    change: First release of the standard
  - version: "1.1"
    date: 2026-09-24
    author: Amish Chadha
    change: Adopt Technology Readiness Levels (section 9) for project maturity
  - version: "1.2"
    date: 2026-09-24
    author: Amish Chadha
    change: Portfolio phase cap (section 10), concept media standard (section 11), CLAUDE.md guardrails
  - version: "1.3"
    date: 2026-09-24
    author: Amish Chadha
    change: Scale figure, interactive 3D viewer and flow diagrams added to concept media; session slash commands
  - version: "1.4"
    date: 2026-09-26
    author: Amish Chadha
    change: Every sheet and render names the project and its GitHub repository; overall dimensions, ISO centre lines and 300 dpi PNG on sheets; titles name the device and view labels state the viewing direction; optional photoreal renders with Blender
  - version: "1.5"
    date: 2026-09-27
    author: Amish Chadha
    change: Product renders (section 12), storefront images and image quality check (section 13), public release and release gate (section 14), authorship, citation and commit signing (section 15)
  - version: "1.6"
    date: 2026-09-29
    author: Amish Chadha
    change: Licensing metadata with REUSE (section 16), Zenodo DOI and Software Heritage archiving (section 17), release gate checks REUSE and a single CITATION.cff license, archive.py
  - version: "1.7"
    date: 2026-09-30
    author: Amish Chadha
    change: Concept and constructable design states; design decisions register (DEC) kept apart from the build plan; prototype build plan (BLD, section 18) with pictures by component is required TRL 3 evidence; every repo targets TRL 3 during the populate phase; build_views.py; /to-trl3 and /build-plan commands
---

# Documentation and drawing standard

Every project in the portfolio uses this standard, so that each precis, write-up and sketch looks the same and carries its own version history. The standard ships as a kit in each repo's `.kit/` folder. The kit version is in `.kit/KIT_VERSION`.

## 1. Document types and IDs

Every controlled document has a unique ID in the form `PRJ-TYP-NNN`.

- `PRJ` is the three-letter project code listed in section 7.
- `TYP` is the document type code from the table below.
- `NNN` is a sequence number within that project and type, starting at 001.

| Code | Type | Typical file |
| --- | --- | --- |
| PRC | Design precis | `docs/02-concept.md` |
| PRB | Problem statement | `docs/01-problem.md` |
| REQ | Requirements | `docs/03-requirements.md` |
| CAL | Calculation or sizing note | `docs/04-calcs/*.md` |
| DDR | Design decision record | `docs/decisions/*.md` |
| BOM | Bill of materials | `bom/bom.csv` |
| DWG | Drawing or sketch sheet | `cad/drawings/*.svg` |
| BLD | Prototype build plan (section 18) | `docs/05-build-plan.md` |
| DEC | Design decisions register (section 18) | `docs/06-design-decisions.md` |
| TST | Test plan or test report (front matter adds `environment: lab` or `relevant`) | `docs/05-tests/*.md` |

Example: `TBK-PRC-001` is the ThermaBrick design precis.

## 2. Revision scheme

| Artifact | While in draft | When released | Change after release |
| --- | --- | --- | --- |
| Documents | 0.1, 0.2, 0.3 ... | 1.0 | 1.1 for minor edits, 2.0 for a design change |
| Drawings | Rev P1, P2 ... (preliminary) | Rev A | Rev B, C ... |

- Every change to a controlled document adds a row to its revision history before the commit.
- The `version` field in front matter always equals the newest row in `revisions`. The renderer rejects a document where they differ.
- Status is one of `Draft`, `In review`, `Released` or `Superseded`. Draft and In review documents print with a status band on every page.
- Every release is tagged in Git as `<doc_id>/v<version>`, for example `TBK-PRC-001/v1.0`. Drawings are tagged `TBK-DWG-001/revA`.
- Git history is the full audit trail. The in-document revision table is the human-readable summary.

## 3. Document front matter

Every Markdown document under version control starts with this block:

```yaml
---
doc_id: TBK-PRC-001
title: ThermaBrick design precis
project: ThermaBrick
doc_type: Precis
version: "0.1"
status: Draft
date: 2026-09-24
author: Amish Chadha
license: CERN-OHL-S-2.0
revisions:
  - version: "0.1"
    date: 2026-09-24
    author: Amish Chadha
    change: Initial draft
---
```

Quote version numbers so YAML keeps `1.0` as text instead of turning it into a number. List revisions newest last.

## 4. Writing style

- Chicago Manual of Style.
- No em dashes. Restructure the sentence instead.
- Lead each section with its conclusion, then support it.
- SI units throughout, in the form `12 kW`, `450 °C`, `3.2 m`. Imperial values may follow in parentheses.
- Number every figure and table ("Figure 2", "Table 1") and give each a caption.
- State every assumption in the calculation that depends on it.
- Put safety notes in a blockquote starting with **Safety:**.

## 5. Visual identity

| Element | Specification |
| --- | --- |
| Typeface | IBM Plex Sans for text, IBM Plex Mono for code and values (SIL Open Font License, bundled in `.kit/fonts`) |
| Ink | `#111827` |
| Secondary text | `#4B5563` |
| Rules and grid | `#D1D5DB` |
| Accent (one only) | `#0F766E` teal |
| Document page | US Letter, 20 mm margins |
| Drawing sheet | ANSI B landscape (431.8 x 279.4 mm) |
| Footer | Document ID, version, status, license and designmolecule.com on every page |

## 6. Drawing and sketch conventions

- Units are millimeters unless the title block says otherwise.
- Third-angle projection, marked with the symbol in the title block.
- Line weights: visible outlines 0.5 mm, hidden lines 0.25 mm dashed, center lines 0.18 mm chain.
- The title block contains the project, title, drawing number, revision, scale, units, projection, sheet, author, date, material or notes, and license.
- Every sheet and every render names the project and its GitHub repository (from `repo:` in `project.yaml`), at the top of the sheet and in the title block, so a printed or forwarded sheet is never anonymous.
- The drawing title names the device, not only the drawing type (for example "Handheld near-infrared resin scanner: general arrangement").
- Every view label states its scale and viewing direction (for example "Scale 1:1; side elevation looking along +Y"), and every isometric or render states where it is seen from.
- Orthographic views generated with `add_ortho` carry overall dimensions (length and depth on the top view, height on the front view) and ISO 128 centre lines on cylinders; hidden lines are dashed. Tolerances are not shown before TRL 4.
- Sheets are exported as SVG, PDF and a 300 dpi PNG.
- The revision table in the top right of the sheet lists every revision.
- Concept sketches use the same sheet and title block and carry the label "CONCEPT, NOT FOR FABRICATION".
- Geometry comes from `cad/src/*.py` (build123d). Sheets are generated by `.kit/drawing.py` and never edited by hand.

## 7. Project codes

| Code | Project | Code | Project | Code | Project |
| --- | --- | --- | --- | --- | --- |
| TBK | ThermaBrick | PCF | PicoFlow | HLT | HelioLite |
| CCB | CharCube | DRN | DustRunner | TRT | TremorTrace |
| STC | StepCue | FXH | FlexHand | CPD | ColdPod |
| SCL | SunClave | STR | SteamRoot | GGD | GrainGuard |
| SDL | SeedLine | ZBX | ZeerBox | RMS | RootMesh |
| DWD | DewDrive | SSK | StillStack | PPR | PotPress |
| WWT | WaterWatch | LMF | LumaFlow | FCL | FieldCell |
| CNP | ConePro | CVC | CulvertCrawl | EGD | EmberGuard |
| SNF | SnapFrame | CGM | CargoMule | SCM | StepClimber |
| SWC | SwapCell | PLP | PalletPilot | FTK | FlatTrike |
| WWK | WaterWalker | GRR | GrowRider | SSP | SunSpoke |
| SGN | StepGen | PBX | PowerBox | WML | WasteWise-ml |
| WSC | WasteWise Scan | RFE | ReflowEconomy | | |
| OHP | Portfolio-wide | | | | |

## 8. Build and publish

- `python .kit/render.py` checks every controlled document and renders it to `docs/pdf/<doc_id>_v<version>.pdf`.
- `python .kit/drawing.py` (called from each project's `cad/src/sheets.py`) builds drawing sheets as SVG and PDF in `cad/drawings/`.
- The GitHub Action in `.github/workflows/docs.yml` runs the checks on every push and attaches PDFs to a GitHub Release whenever a release tag is pushed.
- Public releases follow section 14: `python .kit/release_gate.py` must pass, and the release tag is `v0.<TRL>.0` (for example `v0.3.0` at TRL 3).

## 9. Technology Readiness Level (TRL)

Each project states its maturity as a Technology Readiness Level on the NASA and US DOE 1 to 9 scale. The TRL rates this specific design, not the underlying technology. A sand battery is commercial elsewhere, but a new sand battery design starts at TRL 2 until evidence shows otherwise.

| TRL | Definition | Evidence the repo must contain |
| --- | --- | --- |
| 1 | Basic principles observed | Problem statement (PRB) |
| 2 | Technology concept formulated | Draft precis (PRC) and requirements (REQ) |
| 3 | Analytical or experimental proof of concept | Calculation note (CAL), working build123d model with STEP export, drawing sheet (DWG), priced BOM with every unit cost filled in, prototype build plan (BLD) with pictures, `design_state: constructable` |
| 4 | Components validated in the lab | Test report (TST) with `environment: lab`, build log entries |
| 5 | Validated in a relevant environment | Test report (TST) with `environment: relevant` |
| 6 | System prototype demonstrated in a relevant environment | Precis at version 1.0 or later with status Released, a drawing at a lettered revision (Rev A or later), and a system-level TST with `environment: relevant` |
| 7 to 9 | Operational demonstration through proven in service | Beyond portfolio scope; claim only with a named deployment partner and evidence |

Rules:

- `project.yaml` records `trl` (current level), `trl_target` (the level the current effort aims for) and `trl_evidence` (the files that support the claim).
- `python .kit/render.py --check` fails if the evidence for the claimed TRL is missing. CI runs this check on every push.
- Documentation alone cannot go past TRL 3. TRL 4 and above require hardware and a test report.
- TRL and visibility are independent. A repo can be public at TRL 3 as a documented design ready to build.
- A change of TRL is recorded in the build log with the date and the evidence that justified it.

## 10. Portfolio phase and TRL cap

`.kit/PHASE.yaml` sets the current phase. During the **populate** phase every repo is capped at **TRL 3**: `trl` and `trl_target` may not exceed 3, and the check fails if they do. Every repo targets the cap: `trl_target` must equal 3, so a new repo is taken all the way to TRL 3 (scaffold, populate and advance, see `/to-trl3`). Work that belongs to TRL 4 or later (building or testing hardware, test articles, test plans and reports, build-log entries, purchasing lists, PCB layouts) must not be started. The prototype build plan (BLD, section 18) is TRL 3 paper work and is required. Where it already exists it is kept, flagged in the check output, and not extended. Only Amish changes `PHASE.yaml`.

Every repo carries a `CLAUDE.md` with the working rules for AI sessions: the TRL cap, decision rights (nothing is recorded as decided unless Amish decided it), one step per session, and a mandatory `docs/REVIEW.md` before stopping.

## 11. Concept media

Every repo at TRL 2 or above explains its idea visually. Media are generated from a build123d massing model with `.kit/concept.py`, never drawn by hand, so they stay in step with the design.

| File | Required | Purpose |
| --- | --- | --- |
| `media/hero.png` | TRL 2+ | Shaded isometric render with a 1.75 m person for scale; the website card image |
| `media/concept-blueprint.png` and `.pdf` | TRL 2+ | Blueprint concept sheet: orthographic and isometric views, scale, key figures, title block |
| `media/model.glb` and `media/viewer.html` | TRL 2+ | Interactive 3D viewer (glTF plus model-viewer) for the website |
| `media/cutaway.png` | When the inside matters | Section view showing internal parts |
| `media/exploded.png` | Recommended | Exploded view with numbered callouts matching the BOM |
| `media/flow.png` | When energy or material moves | System, energy or material flow diagram with losses |

Session commands in `.claude/commands/` (`/populate`, `/advance-trl3`, `/rein-in`, `/refresh-media`) carry the standard prompts, so every Claude Code session starts from the same instructions.

At TRL 2 a massing model is enough: correct overall proportions and main components. All concept media carry "CONCEPT, NOT FOR FABRICATION". The check warns when required media are missing at TRL 2 and fails at TRL 3.

## 12. Product renders

Every repo at TRL 3 shows the product as it would look, not only as a massing model.

- `cad/src/product_model.py` is the appearance model. It defines `product_parts()` (named parts with a shape and a material), `TITLE` ("Name: what it is") and `RENDER_VIEWS`. It is for renders only: every main dimension comes from `cad/src/model.py`, never typed in again.
- Where the appearance model departs from `model.py` (a chamfer, a label, a fastener drawn for realism), record the deviation in `docs/REVIEW.md` as "Proposed, awaiting Amish".
- Scale comes from context, not from a floating figure: a hand or forearm for handheld objects, and the posed mannequin (`mannequin()` in `.kit/context_parts.py`: stand, walk, push, ride, sit, reach) for anything a person uses at body scale.
- Renders are made with `.kit/export_views.py` (one scene per view) and `.kit/photoreal.py` (Blender Cycles), then captioned with `.kit/photo_caption.py`. Files are `media/render-<view>.png`; `media/render-hero.png` is required.
- Every caption names the project, the repository and the viewing direction, and carries "CONCEPT, NOT FOR FABRICATION".
- Captions never sit on the render. `.kit/photo_caption.py` adds a header band (title, concept label, repository) above the render and a footer band (view note) below it, wraps every line to the image width, and steps the font down to a floor before adding a line.
- The README opens with `media/render-hero.png`.
- Software-only and scene repositories (no single product) may use a scene render as the hero instead of a product model.

## 13. Storefront images

Two images, both made from `media/render-hero.png` by `python .kit/cards.py .`:

| File | Size | Purpose |
| --- | --- | --- |
| `media/card.png` | 800 x 800 | Square thumbnail for the organization profile page |
| `media/social-preview.png` | 1280 x 640, under 1 MB | GitHub social preview, shown when a repository link is shared |

- The social preview shows the area, name, one-line description, the first sentence of the pitch, the brand line and the repository address. Design Molecule repos read "Design Molecule · open hardware concept, TRL n"; OpenRatio repos read "OpenRatio · research and educational prototype, TRL n".
- GitHub has no API for the social preview. Upload it under the repository's Settings, Social preview, on release day.
- Regenerate both images whenever `render-hero.png` changes.

### Image quality

Every render, card and social preview must be clear and readable. `python .kit/image_qc.py` checks each one, and the release gate blocks on any failure:

| Check | Rule |
| --- | --- |
| Layout | Made by the current `photo_caption.py` or `cards.py`, which store the text layout in the PNG |
| Text inside the image | Every line at least 1.2 % of the image width from each edge; nothing runs off the side |
| No overlap | No line of text touches another line, and no caption text sits on the render |
| Text size | Render captions at least 1.05 % of the image width in pixel height (17 px at 1600 px); social preview text at least 16 px |
| Resolution | Renders at least 1200 px wide; card 800 x 800; social preview 1280 x 640 and under 1 MB |
| Sharpness | The render is not blurred or upscaled (edge sharpness at least 15 on the `image_qc.py` scale) |

Long titles and notes wrap to more lines rather than shrinking below the floor. The social preview shortens the pitch sentence with an ellipsis only if it cannot fit at the smallest size.

## 14. Public release

A repository goes public only when Amish approves it, and only after `python .kit/release_gate.py` passes. The gate checks:

1. `render.py --check` passes (document control, TRL cap, concept media).
2. Storefront: hero render, card, social preview under 1 MB, README leading with the hero, and every image passing the image quality check (section 13).
3. Issue templates in `.github/ISSUE_TEMPLATE/`: question, build report, design suggestion. The build report template restates that the design is a TRL 3 concept, not released for fabrication (OpenRatio: a research and educational prototype, not a medical device).
4. `CITATION.cff` valid, with an author ORCID.
5. License files match `project.yaml`.
6. No em dashes in the repository's own text.
7. BioMedical and OpenRatio repos use soft, non-clinical wording: "research and educational prototype, not a medical device".
8. No secrets anywhere in the history (gitleaks).
9. No links to sibling repositories that are still private.
10. REUSE files present (`REUSE.toml`, `LICENSES/`, `.github/workflows/reuse.yml`) and `reuse lint` passes (section 16).
11. `CITATION.cff` names exactly one license, because Zenodo rejects a list (section 17).

It warns, without blocking, when the README lacks a Safety heading or a "not for fabrication" statement, when `CITATION.cff` has no DOI yet, and when the README lacks the Zenodo DOI, REUSE or Software Heritage badge, so a person can confirm.

On release day, per repository:

- A signed, annotated tag `v0.<TRL>.0` on `main`.
- A GitHub release with short notes (what it is, TRL, status, licenses, how to cite) and a design pack, `<repo>-v0.<TRL>.0-design-pack.zip`, holding `cad/step`, `cad/drawings`, `docs/pdf`, `bom`, README, licenses and `CITATION.cff`.
- Description from the first sentences of `pitch` (350 characters at most), website `https://designmolecule.com` (OpenRatio: `https://openratio.ai`), topics from `project.yaml`.
- Before the first release, the repository is switched on in Zenodo (section 17), so the release is archived and gets a DOI.
- Visibility switched to public last, after the release exists.
- The social preview uploaded and the organization profile updated with the new cards.
- After the release: the concept DOI written to `CITATION.cff` and a Software Heritage save requested (section 17).

The internal working files (`CLAUDE.md`, `.kit/CLAUDE.md`, `.claude/commands/`, `docs/REVIEW.md`) stay public, and open "Proposed, awaiting Amish" items stay visible as open questions (Amish, 2026-09-27).

## 15. Authorship, citation and signing

- Amish Chadha is the author of every design, ORCID 0009-0000-8079-7141. Commits are authored as Amish Chadha <amish@designmolecule.com>.
- `CITATION.cff` lists Amish (with ORCID) first, then any credited contributors; `CONTRIBUTORS.md` and the README Credits section agree with it.
- `CITATION.cff` names one license: the hardware license (CERN-OHL-S-2.0), or the software license in a software-only repository. The full split between hardware and software licenses lives in `REUSE.toml` and the README. Once the repository is archived, `CITATION.cff` carries the concept DOI in `doi:`.
- Work done with Claude carries the trailer `Co-Authored-By: Claude <noreply@anthropic.com>` (with the model name), and the README Credits section says designs are developed with AI assistance.
- Every commit and tag pushed to GitHub is signed with Amish's SSH signing key, so GitHub shows it as Verified. Commits prepared elsewhere are re-signed on Amish's Mac before they are pushed.
- Once a repository is public, its history is never rewritten.

## 16. Licensing metadata (REUSE)

Every file states its copyright and license in a machine-readable way, following the REUSE Specification 3.3 (https://reuse.software). A repository is set up with:

```
python .kit/archive.py reuse
```

This writes three things and adds the REUSE and Software Heritage badges to the README badge line:

- `REUSE.toml`, built from the licenses in `project.yaml`. Everything is under the hardware license by default. Scripts, firmware, notebooks, web viewers, workflows and agent commands are under the software license. `cad/` and `electronics/` stay under the hardware license even where they are written as Python. The bundled IBM Plex fonts are OFL-1.1 (IBM Corp.). Copyright is "<first commit year> Amish Chadha".
- `LICENSES/`, with the full text of each license used (`reuse download`). The root `LICENSE` and `LICENSE-SOFTWARE` files stay for GitHub's license detection.
- `.github/workflows/reuse.yml`, which runs the REUSE check (fsfe/reuse-action) on every push and drives the README badge.

A new kind of file that falls outside these rules gets a new annotation in `REUSE.toml` rather than a header comment. `reuse lint` must pass before every commit that adds files, and the release gate enforces it.

## 17. Archiving and DOI (Zenodo and Software Heritage)

Every public repository is archived twice, so the design stays citable and retrievable if GitHub changes.

Zenodo (a citable DOI for each release):

1. Amish's Zenodo account is linked to GitHub. Before the first release, Amish switches the repository on in Zenodo (Account, GitHub). Only Amish changes Zenodo or GitHub settings.
2. Run `python .kit/archive.py zenodo`: it makes sure `CITATION.cff` names one license and adds the Zenodo DOI badge, which uses the GitHub repository ID and always points at the latest version. Zenodo reads its metadata (title, authors with ORCID, license, keywords) from `CITATION.cff`, and rejects the whole archive when that file lists several licenses.
3. Publish the GitHub release (section 14). Zenodo archives it within minutes and mints two DOIs: a version DOI for that release and a concept DOI that stands for all versions.
4. Check the Zenodo record: title, author and ORCID, license, keywords. If Zenodo shows "Citation metadata load failed", fix `CITATION.cff`, validate it with cffconvert and publish a new patch release (for example `v0.3.2`); a failed release is never re-used.
5. Run `python .kit/archive.py zenodo --doi <concept DOI>` and commit, so GitHub's "Cite this repository" and every future archive carry the concept DOI. Every later release gets its own version DOI automatically; the concept DOI never changes.

Software Heritage (permanent source archive):

1. After the repository is public, request a save at https://archive.softwareheritage.org/save/ (origin type git, the repository URL). Anonymous requests are limited to about ten an hour, so batches are spread out.
2. The Software Heritage badge on the README resolves once the save is accepted and ingested. Later pushes are picked up by its regular crawl.

OpenRatio repositories follow the same steps when Amish approves their release.

## 18. Prototype build plan (BLD) and the constructable design

### Two design states

A design moves through two states, recorded as `design_state` in `project.yaml`:

- **Concept**: the design shows what the product does and that it works on paper (TRL 2 and the calculations of TRL 3). Parts may be simplified shapes that have never been checked for how they are made or how they join.
- **Constructable**: every part can be made with the stated process and material, and every part fits and fastens to the parts next to it. Nothing is left as a shape that cannot be cut, cast, bent, printed, machined or bought.

A repo reaches TRL 3 only when its design is constructable and its build plan shows how. Writing the build plan is how the design is made constructable: when a part cannot be made or cannot fit as modelled, change the model so it can (Amish, 2026-09-30: "fix the design assumptions to match and be physically feasible"), keep what the concept does, and record every change in a decision record "Design for construction" (DDR) and in the plan. Changes that alter what the product does, its pitch or its safety case are proposed, not made.

### What the build plan is

`docs/05-build-plan.md` (`PRJ-BLD-001`) tells a capable maker how to build the first proof-of-concept prototype, in order, component by component, and shows it in pictures. It is written before anything is built, states "Plan, not yet built" under the title and never claims results. Building and testing to it is TRL 4 work.

### Writing rules

- **Plain English.** Say "the steel plate the jack stands on", not a model parameter or variable name. No code identifiers, function names, parameter names or file paths in the body of the plan. Give sizes as numbers with units ("a 62 mm hole, centred 100 mm up from the bottom edge"). The only place file names appear is the closing "Where the numbers come from" list.
- **Pictures first.** Every component and every assembly step has a picture. A reader should be able to build from the pictures, with the words explaining what the pictures cannot show (order, force, tolerance, checks).
- **By component, in build order.** Each component is made and checked before the step that needs it.
- **Cost is not the focus.** One line in the overview may state the parts cost from the BOM; there is no cost or time section.

### Sections, in order

1. **What you are building**: the overview picture (every component pulled apart and numbered in build order) and one short paragraph.
2. **What changed to make it buildable**: a table of each change from the concept (what the concept had, what the constructable design has, why), with a picture where the change is visible. "None" if nothing changed.
3. **Making the components**: one subsection per made component, in build order, each with:
   - its making sketch (three views with overall sizes, a 3D view, where it goes, making notes), `cad/drawings/PRJ-DWG-1NN`;
   - what it is and what it is made from (material, stock size);
   - how to make it, as numbered steps (mark out, cut, drill, bend, weld, cast, print, machine, finish), with the sizes that matter;
   - how it fits the parts next to it: a close-up picture of the joint, which faces touch, what holds them (bolt, weld, pin, clip, glue), the gap or fit needed, and which side goes where;
   - the check before moving on.
   Bought components get a short subsection: what to buy (specification, not brand), and what to do to it (drill, trim, fit).
4. **Putting it together**: numbered assembly steps, each with a step picture (parts already fitted in grey, the part being fitted in colour with an arrow showing the way it goes in), the fasteners, and any hold point.
5. **First checks**: fit, movement, first power or first load, each tied to a requirement ID with a pass criterion. The plan lists them; a TRL 4 test report records them.
6. **Safety stops**: points where work stops (before energising, pressurising, loading, lifting or operating) and what must be true to carry on.
7. **Tools, skills and workspace.**
8. **Where the numbers come from**: the model, drawings, calculation note and BOM, by file name.

### Budgets are value-engineering targets

`budget_usd` in `project.yaml` is a hypothetical control target that keeps the design thinking along a value-engineering lens; it is not a spending limit (Amish, 2026-10-01: "the budgets are a hypothethical control target to ensure we are thinking along a value engineering lens. its ok to ensure wording reflects that the hypothesis budget was x - the real cost being accrued is y"). Write it that way everywhere: "Value-engineering target: USD X. Estimated cost of the constructable design: USD Y (USD Z over or under the target)." A cost requirement is reported against the target ("over the value-engineering target by USD Z"), never as a failure that needs a budget decision, and the design decisions register does not carry "raise the budget" decisions. Instead the register has a short **Value engineering** section: target, estimated cost, the main cost drivers and the savings worth trying.
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

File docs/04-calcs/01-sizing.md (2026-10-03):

---
doc_id: DRN-CAL-001
title: DustRunner sizing calculations
project: DustRunner
doc_type: Calculation
version: "0.6"
status: Draft
date: '2026-10-02'
author: Amish Chadha
license: CERN-OHL-S-2.0
revisions:
- version: "0.1"
  date: '2026-09-25'
  author: Amish Chadha
  change: First issue for TRL 3 (mass, brush contact and deflection, wheel loads and traction, wind, beam, energy, coverage, stopping, cost and payback)
- version: "0.2"
  date: '2026-09-25'
  author: Amish Chadha
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

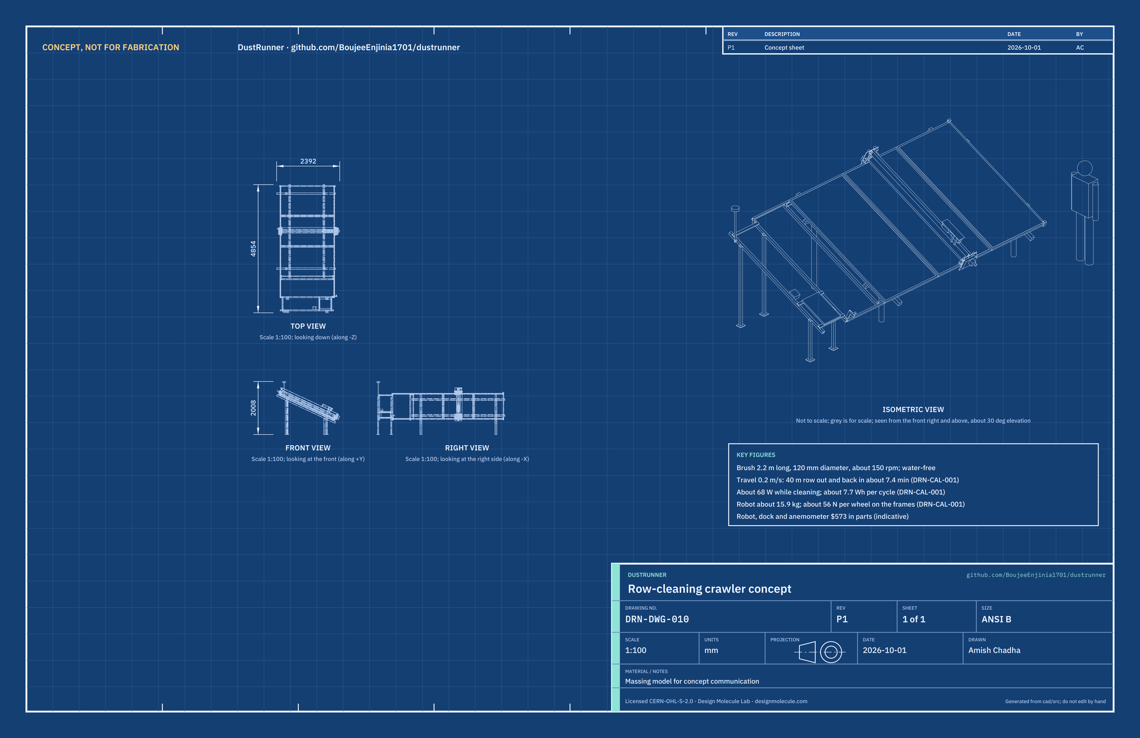
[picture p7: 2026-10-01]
media/concept-blueprint.png

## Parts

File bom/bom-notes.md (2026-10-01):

# BOM notes

- Row numbers match the callouts in `media/exploded.png` and the component table in `docs/02-concept.md` (DRN-PRC-001). Item 15 has no callout.
- All costs are indicative USD prices for one robot, its dock and its anemometer, from typical retail and hobby-supplier prices in 2026. They are not quotes. The supplier column names a supplier type; no supplier is selected yet.
- Total is $573.00 against the $500 `budget_usd` in `project.yaml`, $73.00 over (DRN-CAL-001, I1). Robot items 1 to 10 are $389; dock, end stops and anemometer (items 11 to 14 and 16) $146; wiring and hardware $38. `budget_usd` is unchanged; raising it is proposed, awaiting Amish (DRN-DEC-001).
- TRL 3 changes: item 16, the dock anemometer ($15), is added by DRN-DDR-001 (D3). Item 2 now uses a 50 mm core, item 3 a 0.8 mm hood with a sunshade, item 5 5 mm plates and item 7 springs for 70 N preload (DRN-CAL-001); their prices are unchanged.
- Design for construction (DRN-DDR-003, 2026-09-30): lines 2, 5, 7, 11, 13, 14, 15 and 16 gain the parts that make the design buildable (core end plugs and flange bearings; taller plates, axle flange bearings, couplings and drive housings; roller clevises, hook sliders and spring seats; rail brackets, frame clamp jaws, ties and foot plates; contact post, robot contact bracket and latch solenoid; three-piece stop clamps; beam cleats, hood spacers, sunshade posts, sensor brackets and pack straps; mast clamps). They add $73.00. Hook preload becomes 60 N by the wheel-load rule of DRN-CAL-001 [C0].
- Not included: shipping, tools, spare microfiber sleeves and the PV table itself.
- The legacy scaffold line "Small PV charger" is now items 12 and 13; "Edge-guide rollers" is item 7.

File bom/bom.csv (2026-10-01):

item | qty | spec | supplier | unit_cost_usd | make_buy | notes
1 Chassis beam | 1 | 40 x 80 x 2 mm 6063 aluminum rectangular tube, 2,334 mm between the truck plates (module length plus 56 mm); cut to module length for other tables | Aluminum stockist | 30.00 | buy | Indicative price; about 2.9 kg (DRN-CAL-001 A1); held to each truck plate by two angle cleats (line 15)
2 Microfiber brush | 1 | 120 mm diameter, 2,198 mm brushed length; 50 x 2 mm aluminum core tube with replaceable helical microfiber sleeves; two turned aluminum core end plugs; steel stub shafts (20 mm in the bearings, 15 mm outboard at the lower end); two 20 mm bore pressed-steel 2-bolt flange bearings | Cleaning-supply trade plus local turning shop | 63.00 | make | Indicative price (tube about $15; sleeves about $40; plugs, shafts and flange bearings about $8); 50 mm core keeps the pile interference at 3.5 to 4.4 mm (DRN-CAL-001 B5); sleeves are the only consumable; end plugs and flange bearings added by DRN-DDR-003
3 Brush hood | 1 | 0.8 mm aluminum sheet bent to 77 mm radius over the brush, 2.2 m, with end guards, hung from the beam on five 3 mm spacers; sunshade over the pack and controller from 1 mm sheet on four posts | Local sheet-metal shop | 18.00 | make | Indicative price; about 1.1 kg; spacers and posts in line 15
4 Brush motor and belt drive | 1 | 12 V DC gearmotor, about 60 W, reversible, face-mounted on the lower drive housing; HTD 3M toothed belt and two pulleys (1:1) for about 150 rpm at the brush | Motor distributor | 38.00 | buy | Indicative price; about 48 W electrical in use (DRN-CAL-001 F1)
5 End trucks and wheels (pair) | 1 | Two 5 mm aluminum plates, 260 x 296 mm; four 70 x 18 mm polyurethane wheels at 180 mm wheelbase on 10 mm steel axles, each axle in two 10 mm pressed-steel 2-bolt flange bearings (eight in all); HTD 3M belt and two pulleys per truck; 10 to 6 mm shaft coupling per truck; two folded drive housings (2 mm sheet at the lower truck, 1.5 mm at the upper) that carry the motors and guard the belts | Local fabricator plus bearing supplier | 70.00 | make | Indicative price; wheels ride on the module frame top flange only; plate height, flange bearings, couplings and drive housings added by DRN-DDR-003
6 Drive gearmotors | 2 | 12 V 37 mm gearmotor with Hall encoder, about 10 W, face-mounted on the drive housing and coupled to one wheel axle | Motor distributor | 16.00 | buy | Indicative price; one per truck
7 Guide and hook rollers (set) | 1 | Four 22 mm guide rollers on the frame outer face, each on an M8 bolt in a folded 3 mm aluminum clevis; two 16 mm hook rollers under the frame bottom flange, each on an 8 mm axle in a 10 mm aluminum slider that runs on two M6 shoulder bolts; two compression springs and seats for 60 N preload per truck; sealed bearings with polyurethane tyres | Bearing supplier | 28.00 | buy | Indicative price; preload 60 N by the 60 N wheel-load rule of DRN-CAL-001 [C0]; clevises, sliders and seats added by DRN-DDR-003
8 LiFePO4 pack | 1 | 12.8 V 10 Ah (128 Wh) with BMS, low-temperature and high-temperature charge cut-off, 151 x 65 x 94 mm; strapped to the beam top (straps in line 15) | Battery distributor | 45.00 | buy | Indicative price
9 Controller and motor drivers | 1 | ESP32-class board; dual drive channel and brush motor driver; current sensing; humidity and temperature sensor; latch solenoid driver; IP65 box 140 x 80 x 55 mm screwed to the beam top, and cable glands | Electronics distributor | 49.00 | buy | Indicative price; firmware is a sketch until TRL 4
10 IR edge sensors | 4 | Downward-looking reflective IR sensor in a sealed housing, two per truck, ahead of the wheels, 44 mm above the frame top flange on a folded bracket (line 15) | Electronics distributor | 4.00 | buy | Indicative price
11 Dock frame rails and clamps | 1 | Aluminum C-section rails 780 mm long continuing the module frame profile; three 40 x 40 x 2 mm square-tube cross members 6 mm below the frame bottom; four 4 mm folded rail brackets with spacers and shims; two frame clamps (40 x 6 mm clamp bar, 6 mm jaw, 2.5 mm spacer, M8 bolt) on the first module's long-side frame flange; three 40 x 20 x 2 mm ties; four 40 x 40 x 2 mm legs bolted to the cross members, with foot plates; M8 and M5 bolts | Aluminum stockist plus local fabricator | 60.00 | make | Indicative price; no drilling of modules or structure; cross members kept clear of the hook roller path and rail brackets, clamp jaws and ties added by DRN-DDR-003
12 Dock PV panel | 1 | 20 W monocrystalline, about 530 x 350 mm, bolted through its frame holes to two dock ties | Solar distributor | 22.00 | buy | Indicative price
13 Dock charger and contacts | 1 | LiFePO4 solar charge controller about 5 A in a box on the far cross member; dock contact block with three spring contacts (charge and anemometer signal) on a 40 x 20 mm post; robot contact block with three copper strips on a folded bracket; latch: 6 mm steel pin on a 12 V spring-return pull solenoid on the robot, dropping into a 3 mm latch tab on the dock | Electronics distributor | 35.00 | buy | Indicative price; contact post, robot contact bracket and latch solenoid added by DRN-DDR-003
14 End stops (pair) | 1 | Clamp-on aluminum end stops for the last module's upper and lower frame: top block, outer plate and bottom jaw screwed together around the frame edge, held by an M8 clamp screw; 5 mm rubber buffer; top 40 mm above the glass so the IR sensors pass over | Local fabricator | 12.00 | make | Indicative price; three-piece clamp, clamp screw and lower height by DRN-DDR-003
15 Wiring and hardware | 1 | Silicone wire, 15 A fuse, main switch, two emergency stop buttons in the truck plates, fasteners, cable ties; four 30 x 30 x 3 mm beam cleats; five 3 mm hood spacers; four 12 mm sunshade posts; four folded sensor brackets; two pack straps; M5 rivet nuts | Local hardware and electronics shop | 38.00 | buy | Indicative price; no exploded-view callout; cleats, spacers, posts, brackets and straps added by DRN-DDR-003
16 Dock anemometer | 1 | Cup anemometer with pulse output, 0 to 30 m/s, on a vertical 24 mm mast held by two U-bolt clamps to the dock's far cross member; read by the robot through the third dock contact before each start | Electronics distributor (weather-station spare part) | 17.00 | buy | Indicative price; added by DRN-DDR-001 D3; vertical mast and clamps by DRN-DDR-003

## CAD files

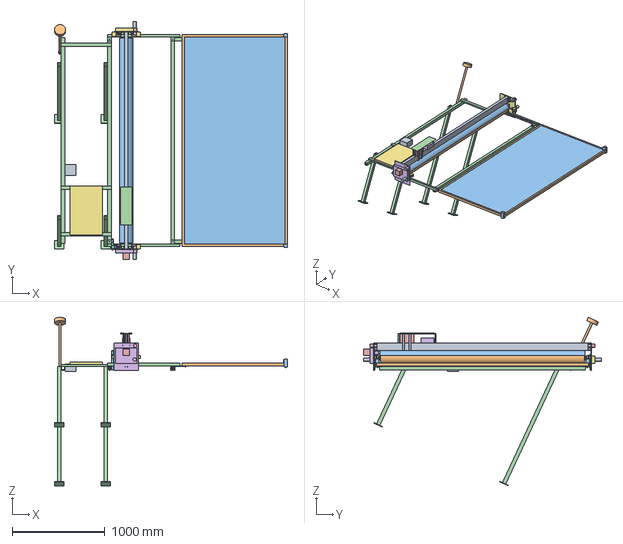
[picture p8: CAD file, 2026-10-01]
cad/step/dustrunner-assembly.step
2506.0 x 2556.0 x 1812.5 mm

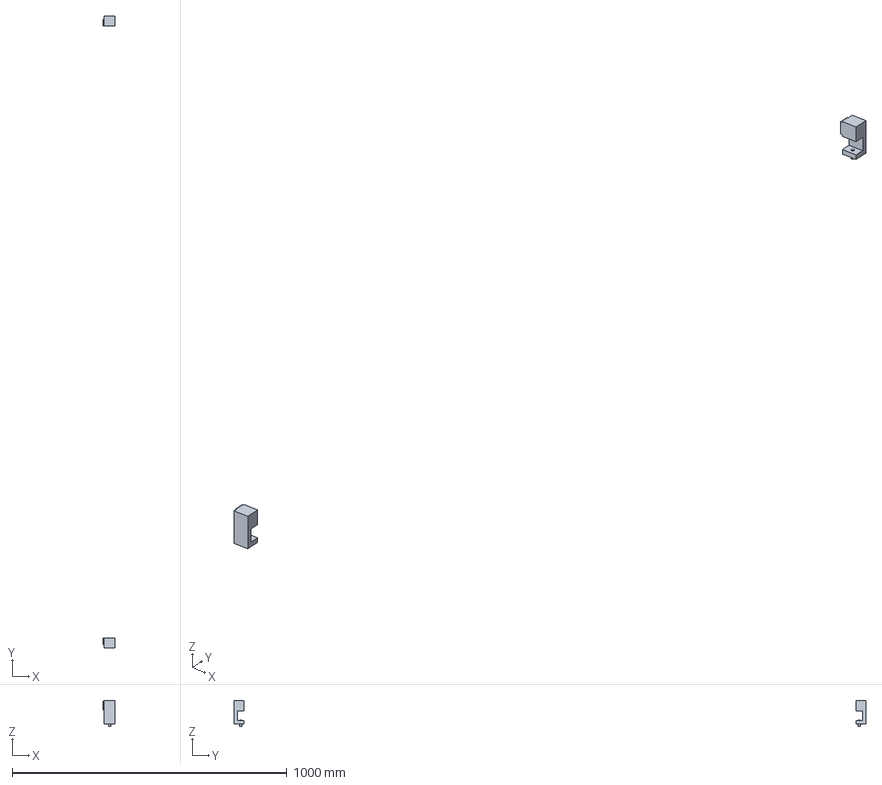
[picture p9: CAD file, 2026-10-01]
cad/step/dustrunner-end-stop.step
45.0 x 2302.0 x 96.0 mm

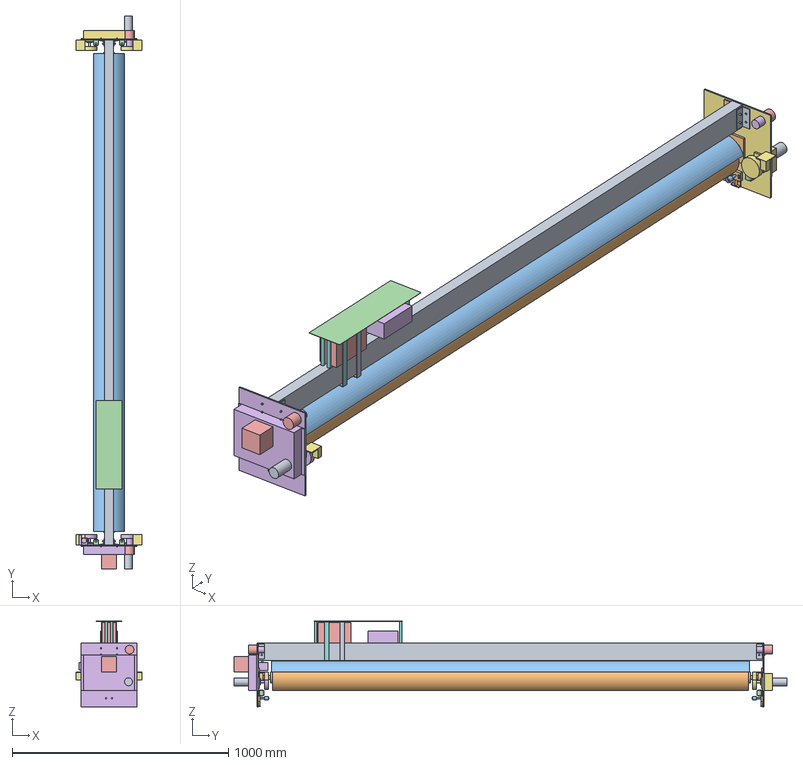
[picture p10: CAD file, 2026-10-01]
cad/step/dustrunner-robot.step
304.0 x 2556.0 x 396.3 mm

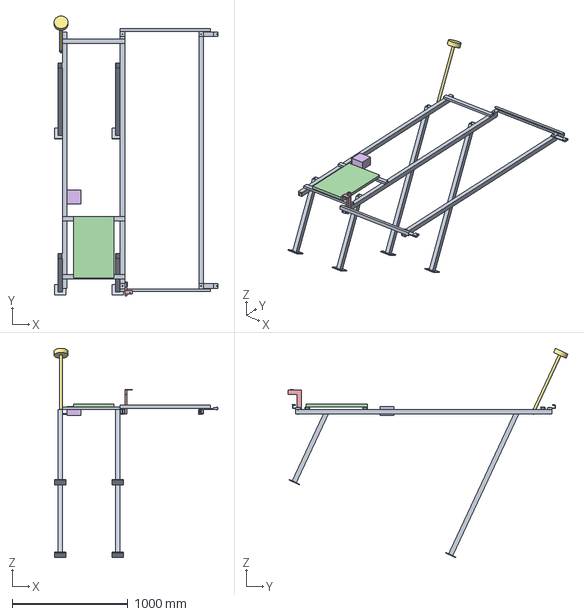
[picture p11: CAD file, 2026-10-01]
cad/step/dustrunner-dock.step
1417.0 x 2422.9 x 1812.5 mm

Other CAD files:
cad/stl/dustrunner-dock.stl
cad/stl/dustrunner-end-stop.stl
cad/stl/dustrunner-robot.stl

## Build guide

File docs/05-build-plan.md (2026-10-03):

---
doc_id: DRN-BLD-001
title: DustRunner prototype build plan
project: DustRunner
doc_type: Build plan
version: "0.3"
status: Draft
date: '2026-10-02'
author: Amish Chadha
license: CERN-OHL-S-2.0
revisions:
  - version: "0.1"
    date: '2026-09-30'
    author: Amish Chadha
    change: First build plan, with pictures by component and step; design made constructable (DRN-DDR-003)
  - version: "0.2"
    date: '2026-10-01'
    author: Amish Chadha
    change: Budget treated as a value-engineering target
  - version: "0.3"
    date: '2026-10-02'
    author: Amish Chadha
    change: 'General arrangement reissued at Rev P4; no change to the steps or pictures'
---

# DustRunner prototype build plan

**Plan, not yet built.** How to build the first proof-of-concept prototype, component by component. Building and testing to it is TRL 4 work. Decisions still to be made are kept in the design decisions register ([docs/06-design-decisions.md](06-design-decisions.md)), not here.

## 1. What you are building

Figure 1. The robot, pulled apart and numbered in build order

*Figure 1. The robot pulled apart and numbered in build order. The long middle of the beam, brush and hood is left out so the trucks can be seen.*

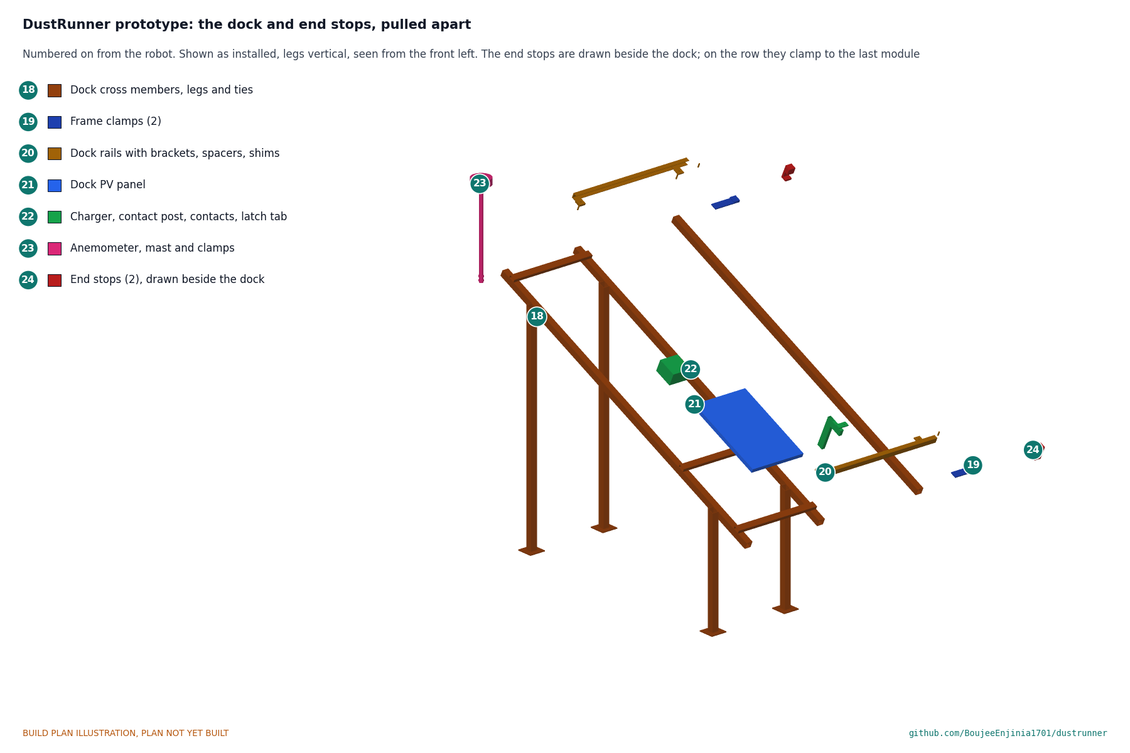
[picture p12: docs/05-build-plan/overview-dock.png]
Figure 2. The dock and end stops, pulled apart


*Figure 2. The dock and the end stops, numbered on from the robot, shown as installed.*

The prototype is one DustRunner robot for the reference table (portrait modules 2,278 mm long, 25° tilt), its dock at the start of the row and a pair of end stops at the far end. The robot is a 2.3 m aluminium beam carrying a microfiber brush between two end trucks; each truck has two driven wheels on the module frame's top flange, two guide rollers on the frame's outer face and a sprung hook roller under its bottom flange, with the motors and belts in a folded drive housing outside. The dock is a small aluminium frame on four legs, clamped to the first module's frame, whose two short rails continue the frame profile; it carries a 20 W panel, a charger, the contact block the robot parks against, a latch tab and a cup anemometer. Figures 1 and 2 show the 24 components in the order you make or fit them. Nineteen are made in a small workshop from aluminium plate, sheet, tube, angle and bar, with sawing, drilling, tapping, folding and a little turning (Section 3); the rest are bought: wheels, bearings, belts and pulleys, gearmotors, rollers, the pack, the controller and drivers, sensors, the solenoid, the panel, the charger and the anemometer. The parts cost about $573 from the bill of materials, against a value-engineering target of $500.

> **Safety:** DustRunner is moving machinery with an unattended rotating brush, belts and wheels, a 128 Wh lithium iron phosphate pack, and it works on a live PV array that can carry several hundred volts DC, on glass up to about 75 °C, up to about 1.6 m above the ground. Keep the pack fuse out until Section 6 says otherwise, never charge the pack below 0 °C or above 45 °C, and never let the robot touch array cables, connectors or junction boxes. Cut aluminium edges are sharp: deburr everything and wear gloves when handling plate and sheet.

## 2. What changed to make it buildable

The concept showed what DustRunner does; many of its parts floated, rubbed or had no fixing. Each change below keeps what the robot and dock do, and all of them are recorded in decision record DRN-DDR-003, open for Amish's review.

*Table 1. Changes from the concept.*

| Component | The concept had | The buildable design has | Why |
| --- | --- | --- | --- |
| Guide rollers | A roller filling the gap between the truck plate and the frame face, with no axle | A roller on an M8 bolt in a folded clevis; the plate sits 28 mm (not 22) outside the frame (Figure 7) | The roller turns freely, 6 mm off the plate |
| Hook rollers | A roller floating over a rigid arm, with no spring | A sliding block on the plate, pushed up by a spring, carrying the roller on an 8 mm axle under the flange (Figure 9) | Gives the set preload, now 60 N per truck |
| Wheel axles and motors | Stub axles on the inside, a belt on the outside, motors fixed to nothing | Each axle in two flange bearings through the plate; belts and motors in a folded drive housing on the outside (Figures 4 and 16) | The housing guards the belts and holds the motors |
| Brush ends | Shafts butted against the core, no bearings | Turned plugs in the core, stub shafts in the plugs, one flange bearing on each plate (Figure 16) | The shafts can carry the brush and its drive |
| Beam | Butted against the plates, no fixing | Two angle cleats at each end, through-bolted (Figure 13) | Bolted, so the beam can be replaced for another module length |
| Hood, sunshade, pack | Floating a few millimetres from the beam | Hood on five 3 mm spacers; shade on four posts; pack strapped (Figure 18) | Keeps the gaps the concept meant |
| Sensors, robot contacts | Butted against the plate edge | On folded brackets screwed to the plate face (Figures 10 and 11) | Fixed to a face, not an edge |
| Dock latch | A pin with nothing to engage and no release | A sprung pin on a 12 V solenoid on the robot drops through a tab on the dock (Figure 30) | Holds the parked robot in wind; fails latched |
| Dock rails and supports | Posts under the rails in the hook roller's path; cross members not touching the rails; clamps not touching anything | Rails held by brackets inside the channel on cross members 6 mm lower; frame clamps grip the first module's flange (Figures 22 and 25) | The robot can drive out, and the dock is fixed without drilling |
| Dock legs, mast | Legs meeting tilted members at an angle; the mast leaning 25° | Vertical legs bolted beside the members, on foot plates; vertical mast in U-bolt clamps (Figure 28) | Bolted at any tilt; the anemometer reads correctly upright |
| End stops | Taller than the sensors, so a sensor hit first; no clamp screw | Three-piece clamp with an M8 screw, top 40 mm above the glass (Figure 32) | The wheels meet the buffer; the sensors pass over |

## 3. Making the components

Make and check each component before the assembly step that needs it. Sizes are in millimetres. "Inner face" of a truck plate is the face toward the brush; "outer face" is the face away from it. "Toward the row" and "toward the dock" are along the row; "up" on a truck plate is measured from its bottom edge. Workshop tolerance is 0.5 mm unless a step says otherwise; drawings do not carry tolerances before TRL 4. Folding 2 and 3 mm aluminium needs a sheet-metal brake (a local sheet-metal shop, or a bench brake); the short 3 mm folds can be made in a vice between two hardwood blocks.

### 3.1 Truck plates (make 2, a lower and an upper)

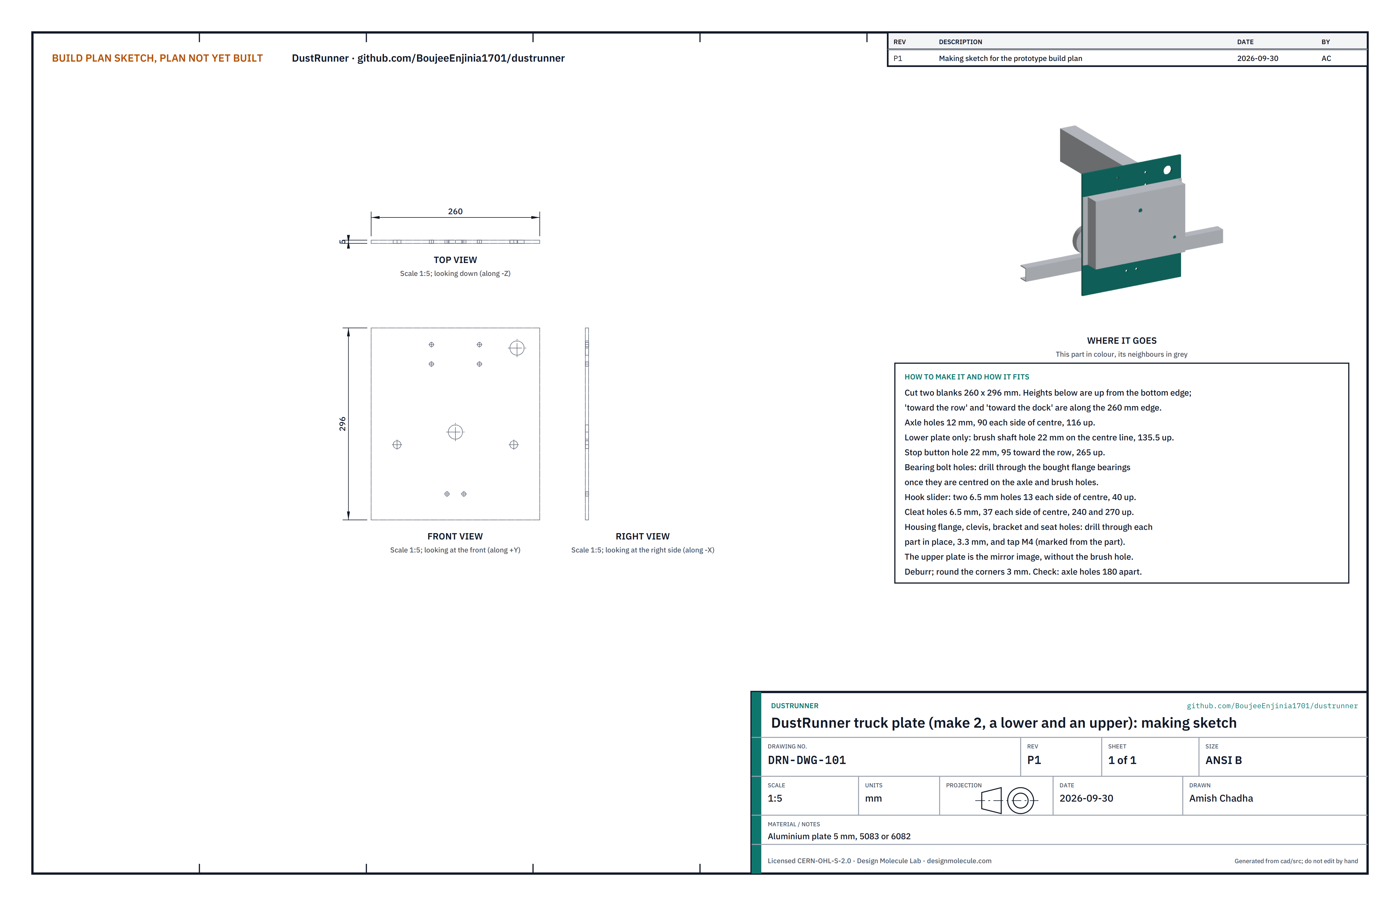
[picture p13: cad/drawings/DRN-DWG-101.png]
Figure 3. Making sketch of the truck plate


*Figure 3. Truck plate making sketch (DRN-DWG-101).*

**What it is and what it is made from.** The plate at each end of the robot that everything on that truck bolts to. Aluminium plate 5 mm, 5083 or 6082 class, 260 x 296 mm.

**How to make it.**

1. Cut two blanks 260 x 296 mm, square. Mark one face of each as the inner face and the long edges as top and bottom.
2. Axle holes: 12 mm, 90 each side of the centre line, 116 up. Drill the two plates clamped together.
3. Lower plate only: brush shaft hole 22 mm on the centre line, 135.5 up.
4. Stop button hole: 22 mm, 95 toward the row from the centre line, 265 up.
5. Hook slider bolts: two 6.5 mm holes, 13 each side of the centre line, 40 up.
6. Beam cleat bolts: four 6.5 mm holes, 37 each side of the centre line, 240 and 270 up.
7. All other holes (flange bearings, drive housing flanges, clevises, sensor and contact brackets, spring seat) are drilled through the part in place, 3.3 mm and tapped M4, or 6.5 mm where the part's bolt is M6. Mark them from the part when you fit it.
8. The upper plate is the mirror image of the lower, without the brush hole. Deburr every hole and round the corners to about 3 mm.

**How it fits the parts next to it.**

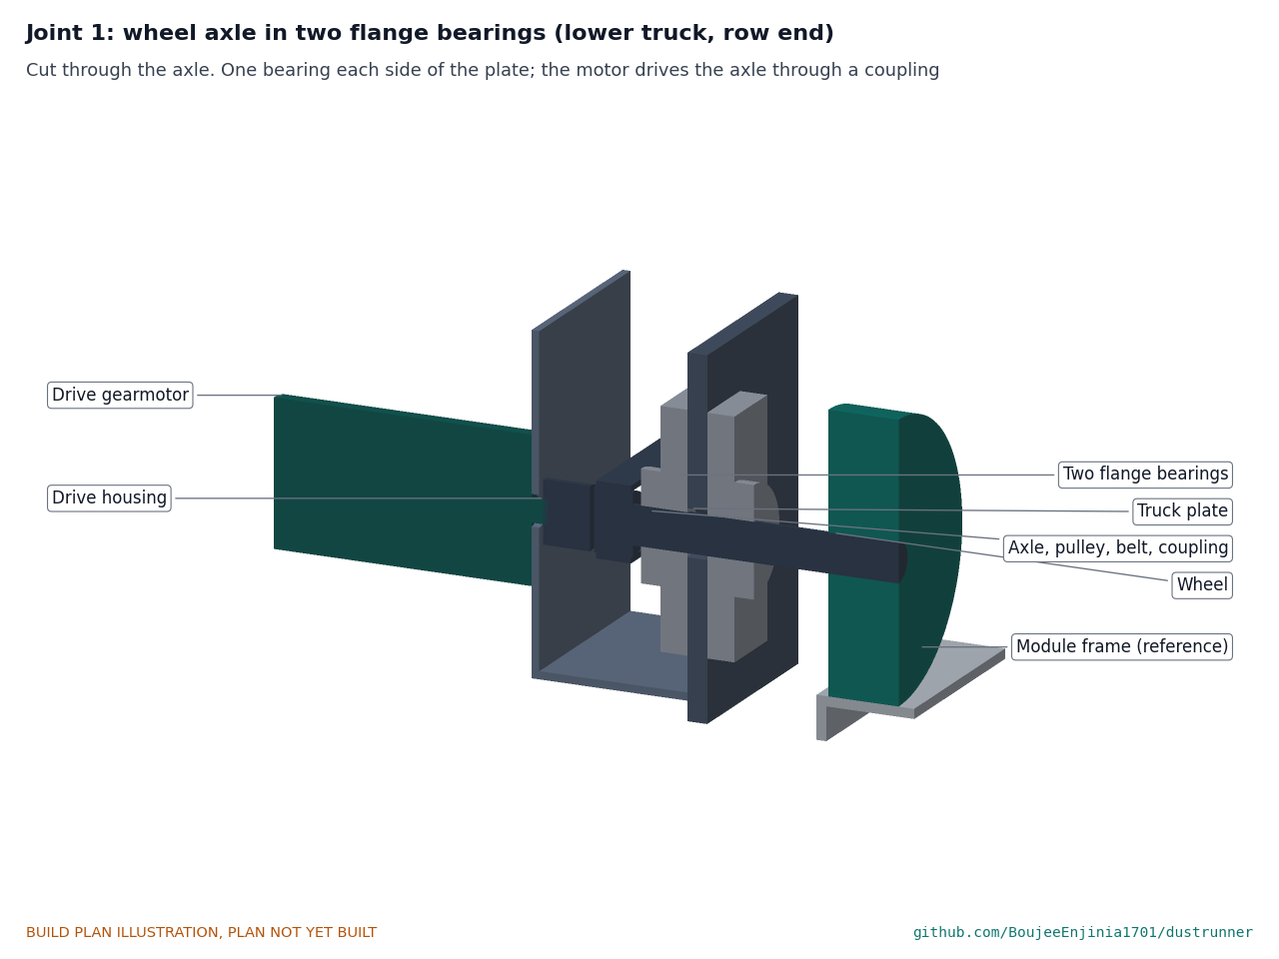
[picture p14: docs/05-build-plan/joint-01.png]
Figure 4. Joint 1: wheel axle in two flange bearings


*Figure 4. Cut through the axle: a flange bearing each side of the plate, the wheel on the inside, the pulley and the motor coupling inside the drive housing.*

Each axle turns in two 2-bolt flange bearings, one bolted to each face of the plate, so the wheel overhangs only 19 mm past the inner bearing. The wheel runs on the frame's top flange, 3 to 21 from the frame's outer face; the plate stands 28 mm outside the frame and never touches it.

**Check before moving on.** Axle holes 180 apart within 0.5 mm; an axle pushed through both holes of the two plates clamped together turns freely.

### 3.2 Drive housings (make 2: a lower and an upper)

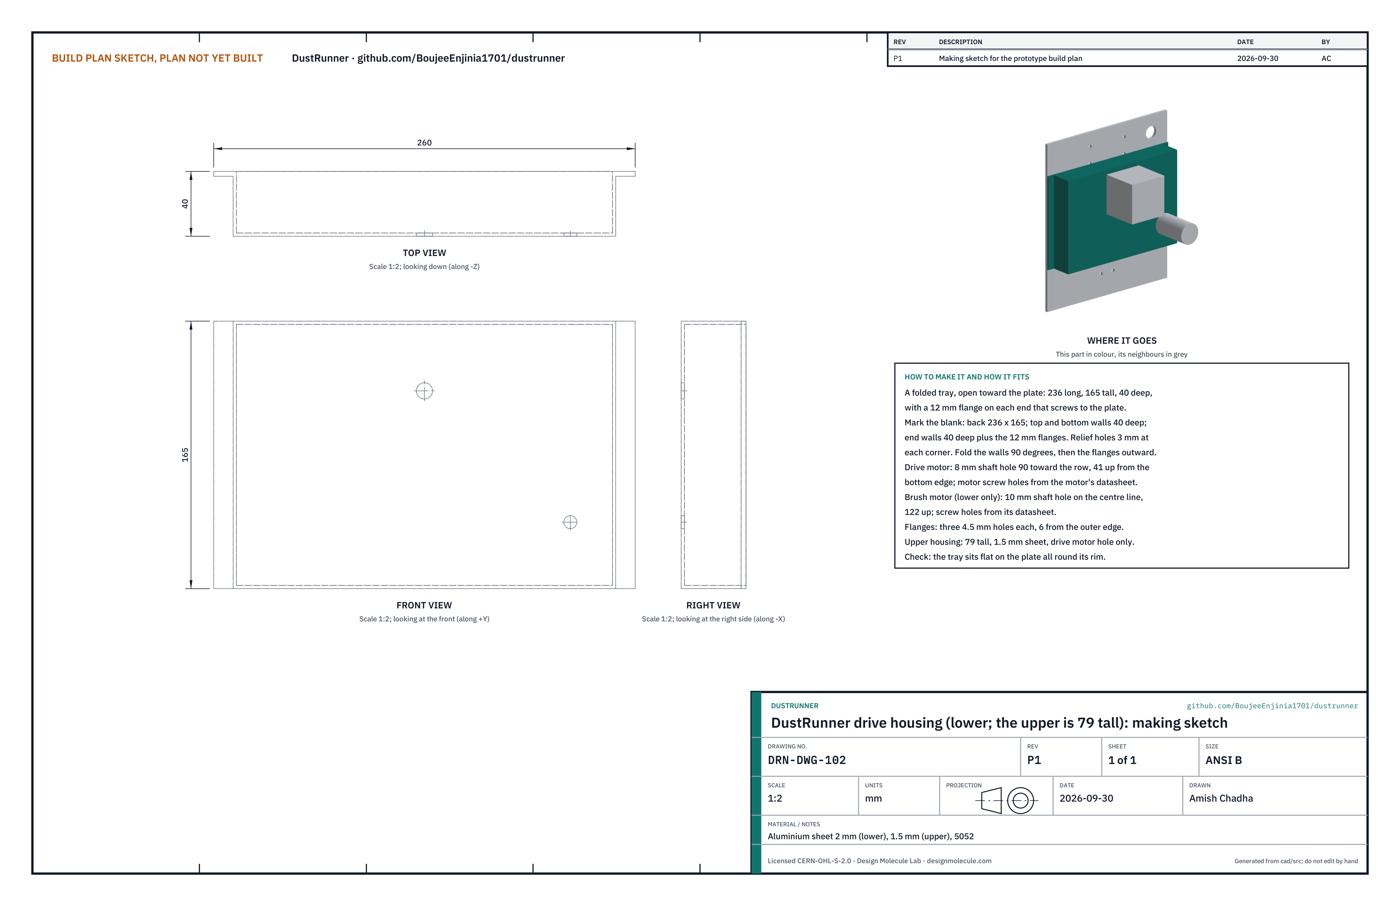
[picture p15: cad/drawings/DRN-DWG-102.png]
Figure 5. Making sketch of the drive housing


*Figure 5. Lower drive housing making sketch (DRN-DWG-102). The upper housing is the same but 79 tall.*

**What it is and what it is made from.** A folded tray on the outer face of each truck plate that covers the wheel belt (and, at the lower truck, the brush belt) and carries the gearmotors. Aluminium sheet 5052: 2 mm for the lower housing, which carries the brush motor; 1.5 mm for the upper.

**How to make it.**

1. Mark the lower blank: a back 236 x 165; top and bottom walls 40 deep; end walls 40 deep plus a 12 mm flange on each. Drill a 3 mm relief hole at each corner where fold lines cross.
2. Fold the walls 90° toward you, then the flanges 90° outward.
3. Drive motor shaft hole: 8 mm, 90 toward the row from the centre, 41 up from the bottom edge. Motor screw holes from the gearmotor's datasheet, centred on it.
4. Lower housing only: brush motor shaft hole 10 mm on the centre line, 122 up, with the brush motor's screw holes round it.
5. Three 4.5 mm holes in each flange, 6 from the outer edge.
6. The upper housing is the same with a back 236 x 79 and the drive motor hole only.

**How it fits the parts next to it.** The open side faces the plate's outer face; the flanges screw to the plate with M4 screws and the rim sits flat on the plate all round. The drive gearmotor bolts face-on to the outer wall and its shaft joins the axle through a 6 to 10 mm coupling (Figure 4). At the lower truck the brush gearmotor bolts above it and drives the brush shaft through a 1:1 toothed belt in a second layer (Figure 16).

**Check before moving on.** The tray sits flat on the plate all round; both belts turn by hand without touching the walls.

### 3.3 Guide roller clevises (make 4)

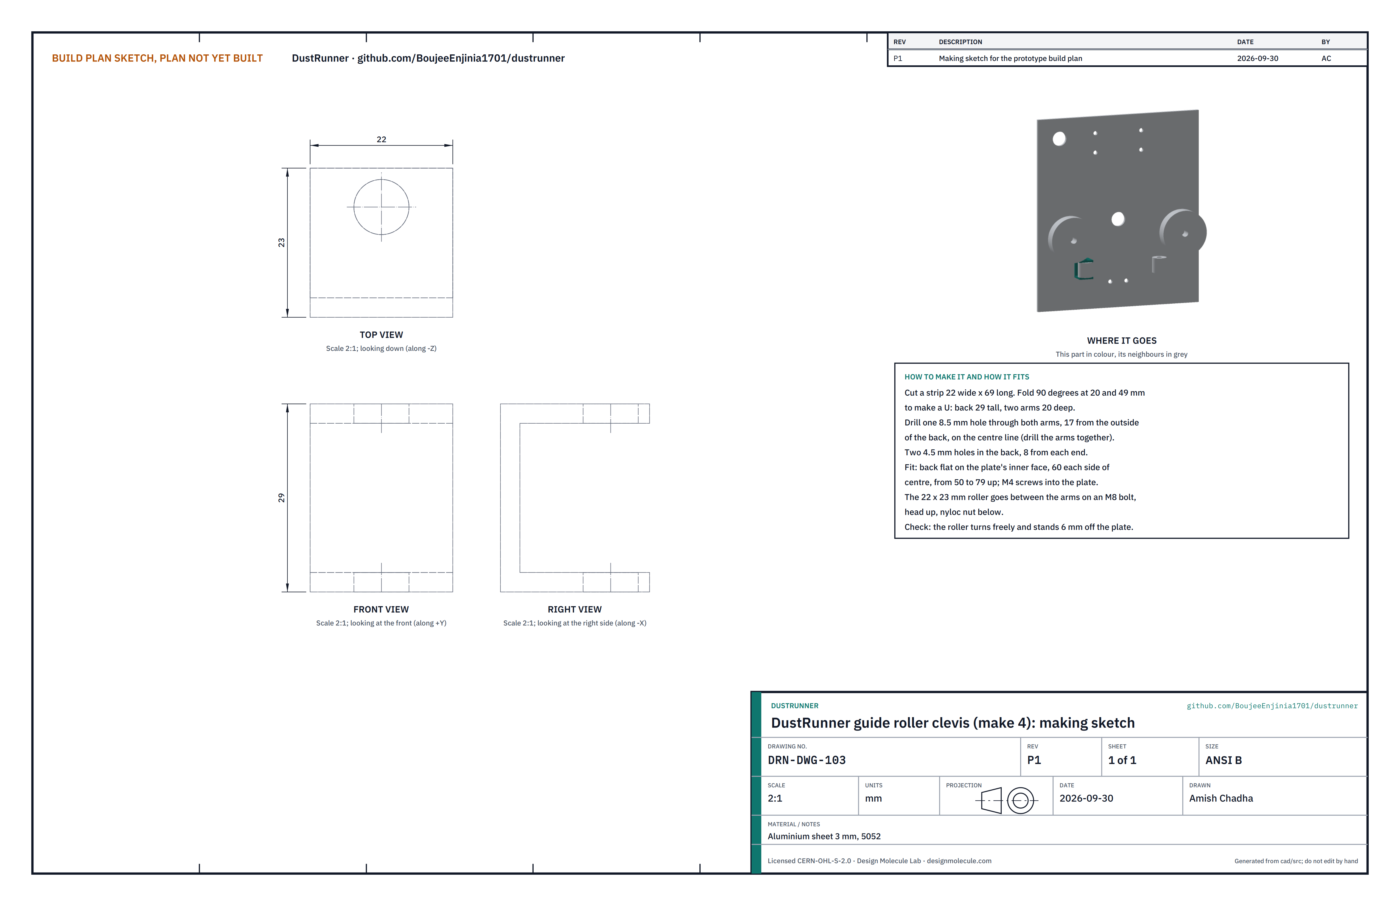
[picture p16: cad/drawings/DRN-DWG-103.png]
Figure 6. Making sketch of the guide roller clevis


*Figure 6. Guide roller clevis making sketch (DRN-DWG-103).*

**What it is and what it is made from.** A small U bracket that carries a guide roller against the frame's outer face. Aluminium sheet 3 mm, 5052.

**How to make it.**

1. Cut four strips 22 x 69. Fold each 90° at 20 and 49 to make a U with a 29 mm back and two 20 mm arms.
2. Drill one 8.5 mm hole through both arms, 17 from the outside of the back, on the centre line, with the arms clamped together.
3. Drill two 4.5 mm holes in the back, 8 from each end.

**How it fits the parts next to it.**

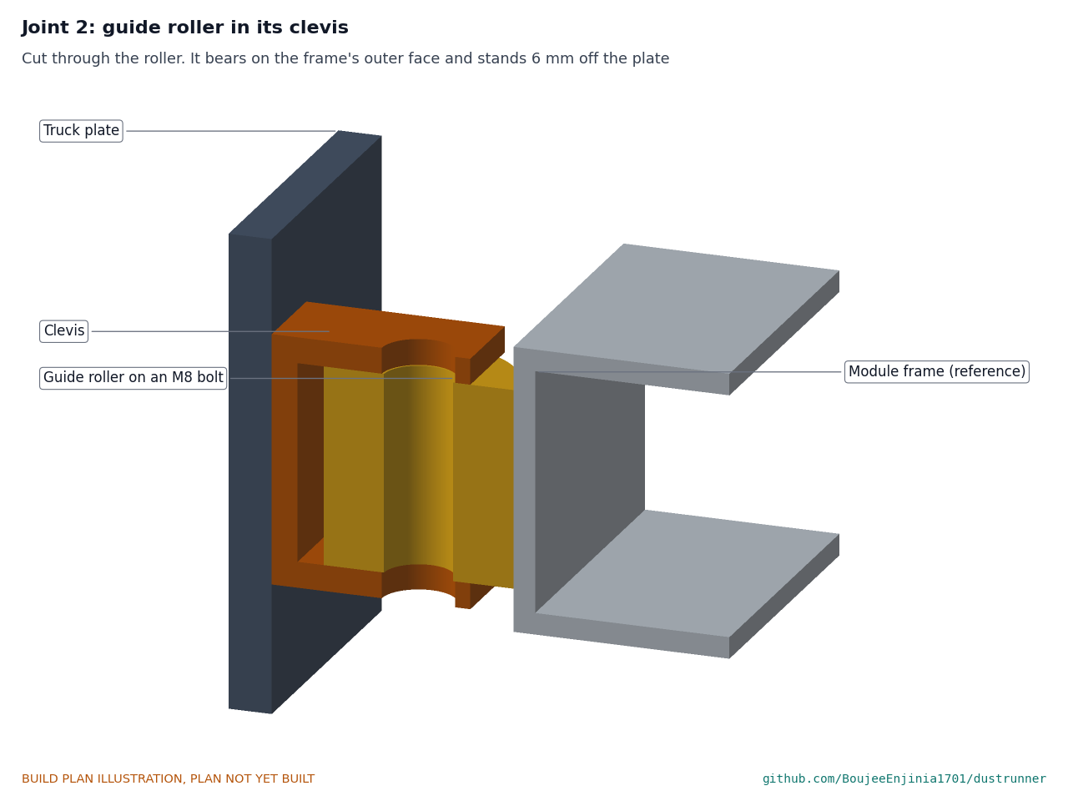
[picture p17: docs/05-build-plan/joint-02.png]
Figure 7. Joint 2: guide roller in its clevis


*Figure 7. Cut through the roller: the clevis back on the plate, the roller between the arms on its bolt, bearing on the frame's outer face.*

The back screws flat to the plate's inner face, 60 each side of the centre line, from 50 to 79 up. The 22 mm roller turns between the arms on an M8 bolt, head up and nyloc nut below; it bears on the frame's outer face and stands 6 mm off the plate. The upper arm stays 5 mm clear of the frame's top corner.

**Check before moving on.** The roller turns freely and the arms are parallel.

### 3.4 Hook sliders and spring seats (make 2 of each)

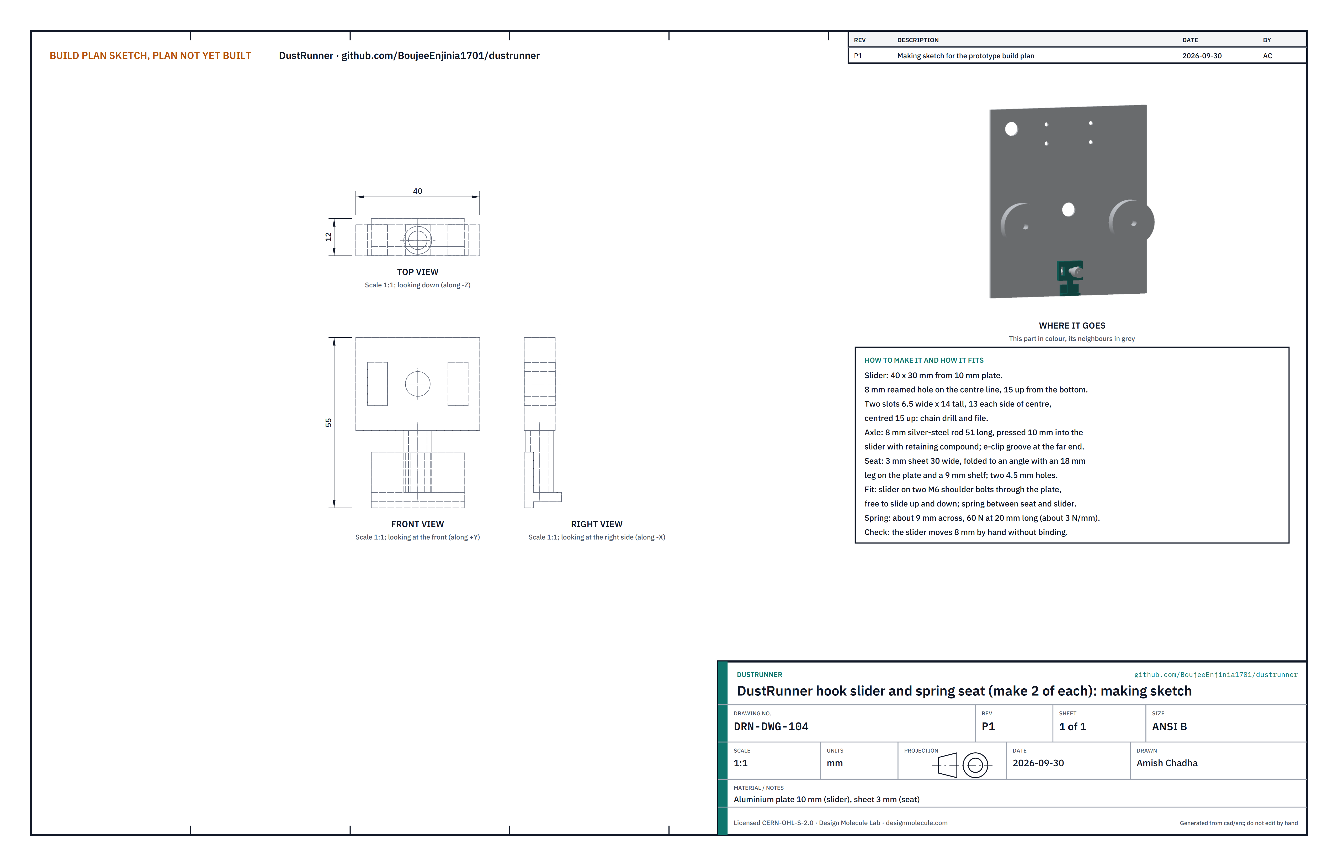
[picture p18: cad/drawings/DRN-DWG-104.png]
Figure 8. Making sketch of the hook slider and spring seat


*Figure 8. Hook slider and spring seat making sketch (DRN-DWG-104).*

**What it is and what it is made from.** The sliding block that holds the hook roller up under the frame's bottom flange, and the bracket its spring pushes from. Aluminium plate 10 mm (slider); 3 mm sheet (seat); 8 mm silver-steel rod (axle).

**How to make it.**

1. Slider: cut 40 x 30 from 10 mm plate. Ream an 8 mm hole on the centre line, 15 up from the bottom.
2. Cut two slots 6.5 wide and 14 tall, 13 each side of the centre line, centred 15 up: chain drill and file.
3. Axle: cut 8 mm silver steel 51 long; cut an e-clip groove 2 from one end. Press the other end 10 mm into the slider with retaining compound.
4. Seat: fold 3 mm sheet 30 wide into an angle with an 18 mm leg and a 9 mm shelf; two 4.5 mm holes in the leg.

**How it fits the parts next to it.**

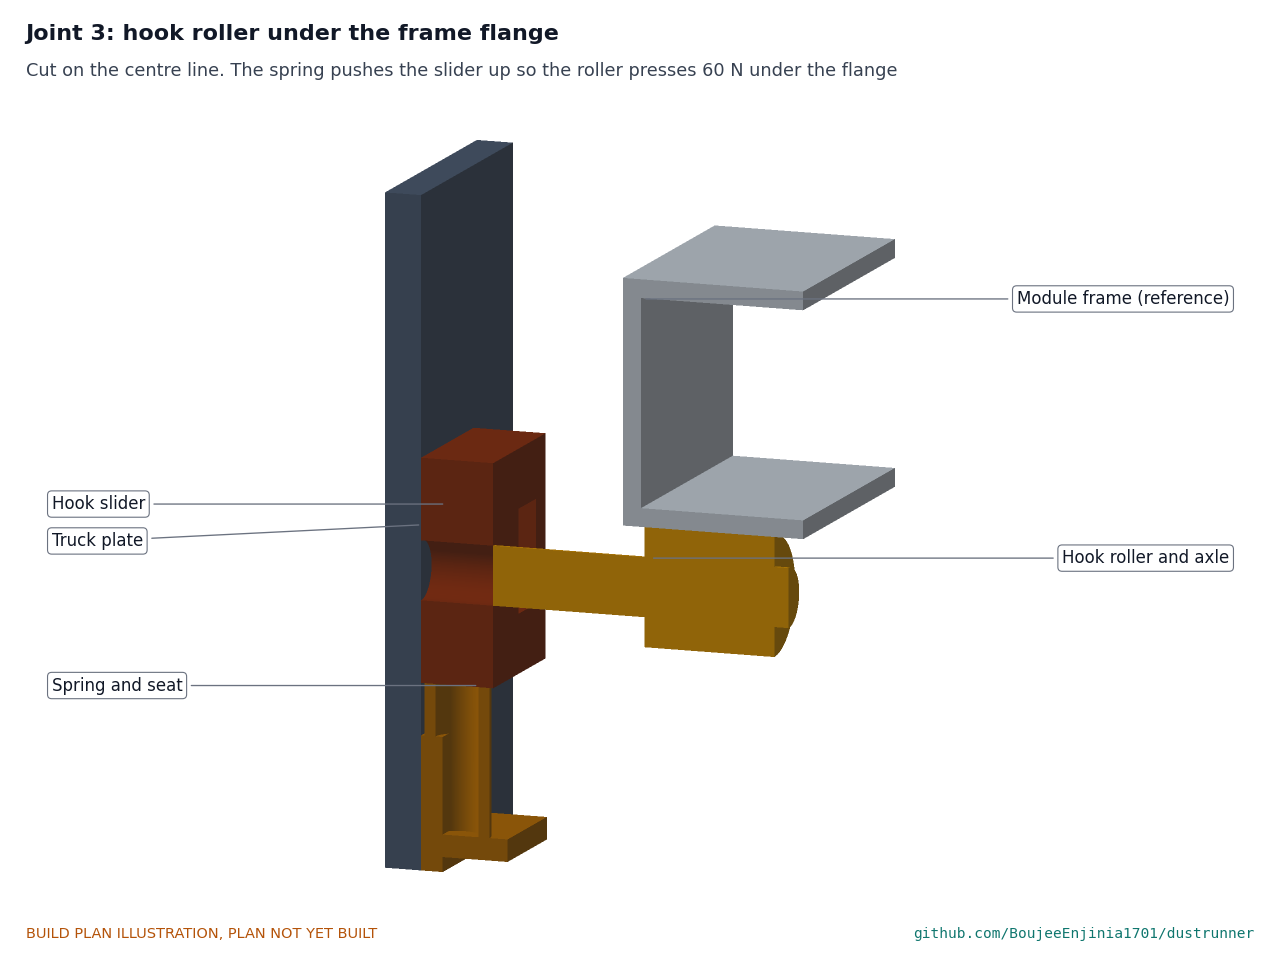
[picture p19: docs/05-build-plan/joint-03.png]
Figure 9. Joint 3: hook roller under the frame flange


*Figure 9. Cut on the centre line: slider on the plate, the roller under the frame's bottom flange, the spring below the slider.*

The slider sits flat on the plate's inner face on two M6 shoulder bolts through its slots, free to slide about 8 mm up and down. The 16 x 18 mm roller turns on the axle under the frame's bottom flange, 3 to 21 from the frame's outer face; the axle passes 4 mm under the frame web. The seat screws to the plate below the slider and a compression spring about 9 mm across stands between them. Choose the spring to give 60 N at 20 mm long (about 3 N/mm); the robot weighs more than the concept, so 60 N, not 70 N, keeps each wheel at 60 N or less.

**Check before moving on.** The slider moves by hand without binding; the roller is square to the slider.

### 3.5 IR sensor brackets (make 4: two right-hand, two left-hand)

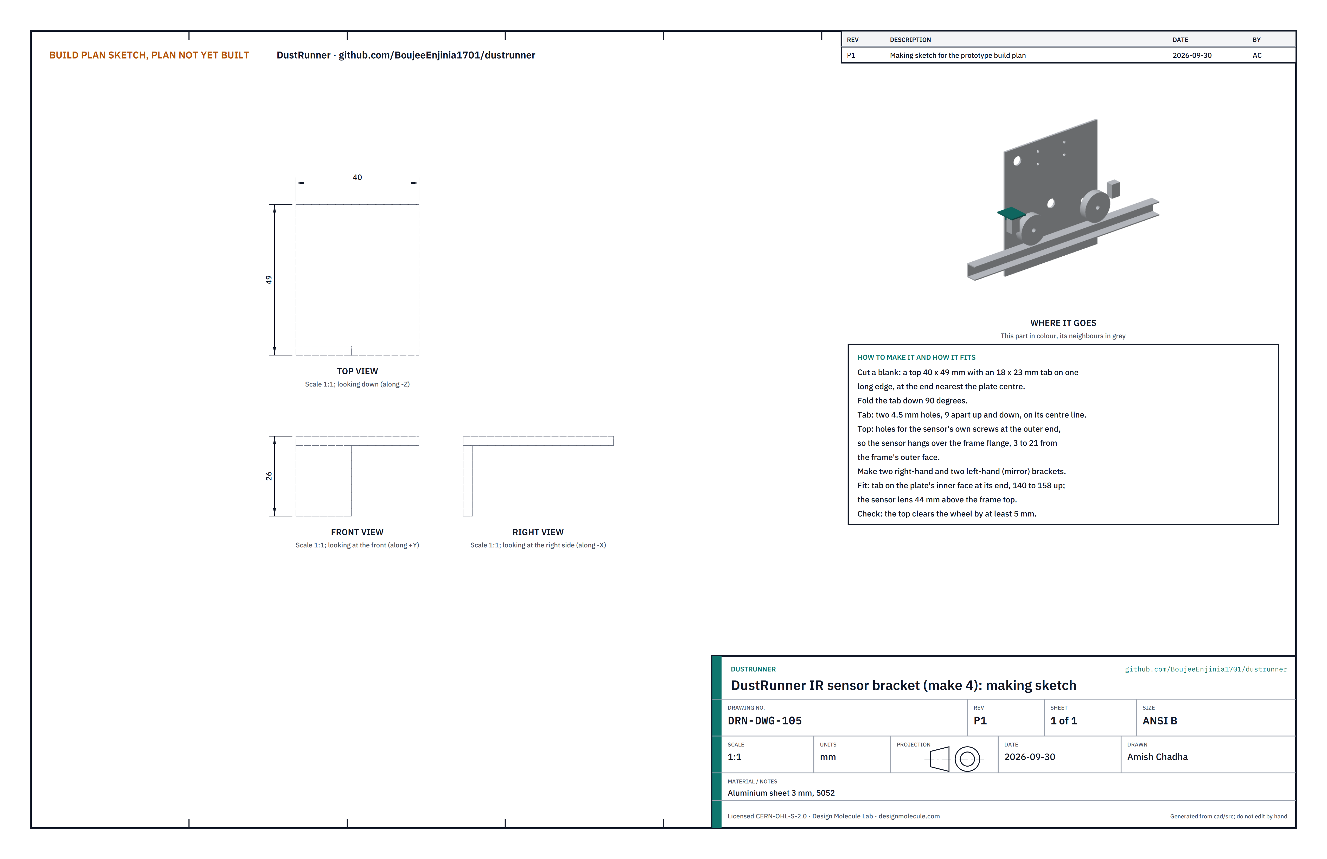
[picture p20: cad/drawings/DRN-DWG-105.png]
Figure 10. Making sketch of the IR sensor bracket


*Figure 10. IR sensor bracket making sketch (DRN-DWG-105).*

**What it is and what it is made from.** A folded bracket that holds an edge sensor ahead of each wheel, looking down at the frame's top flange. Aluminium sheet 3 mm, 5052.

**How to make it.**

1. Cut a blank: a top 40 x 49 with an 18 x 23 tab on one long edge, at the end nearest the plate centre. Make two, and two mirror images.
2. Fold the tab down 90°. Drill two 4.5 mm holes in the tab, 9 apart, on its centre line.
3. Drill the top for the sensor's own screws at its outer end.

**How it fits the parts next to it.** The tab screws to the plate's inner face at each end of the plate, 140 to 158 up; the top runs inward over the frame and the sensor hangs from it, its lens 44 mm above the frame's top flange, over the wheel track. The top clears the wheel by 12 mm. At the far end the sensor passes 5 mm over the end stop (Figure 32).

**Check before moving on.** The sensor sits square over the flange, 3 to 21 from the frame's outer face.

### 3.6 Contact and latch bracket (make 1, lower truck only)

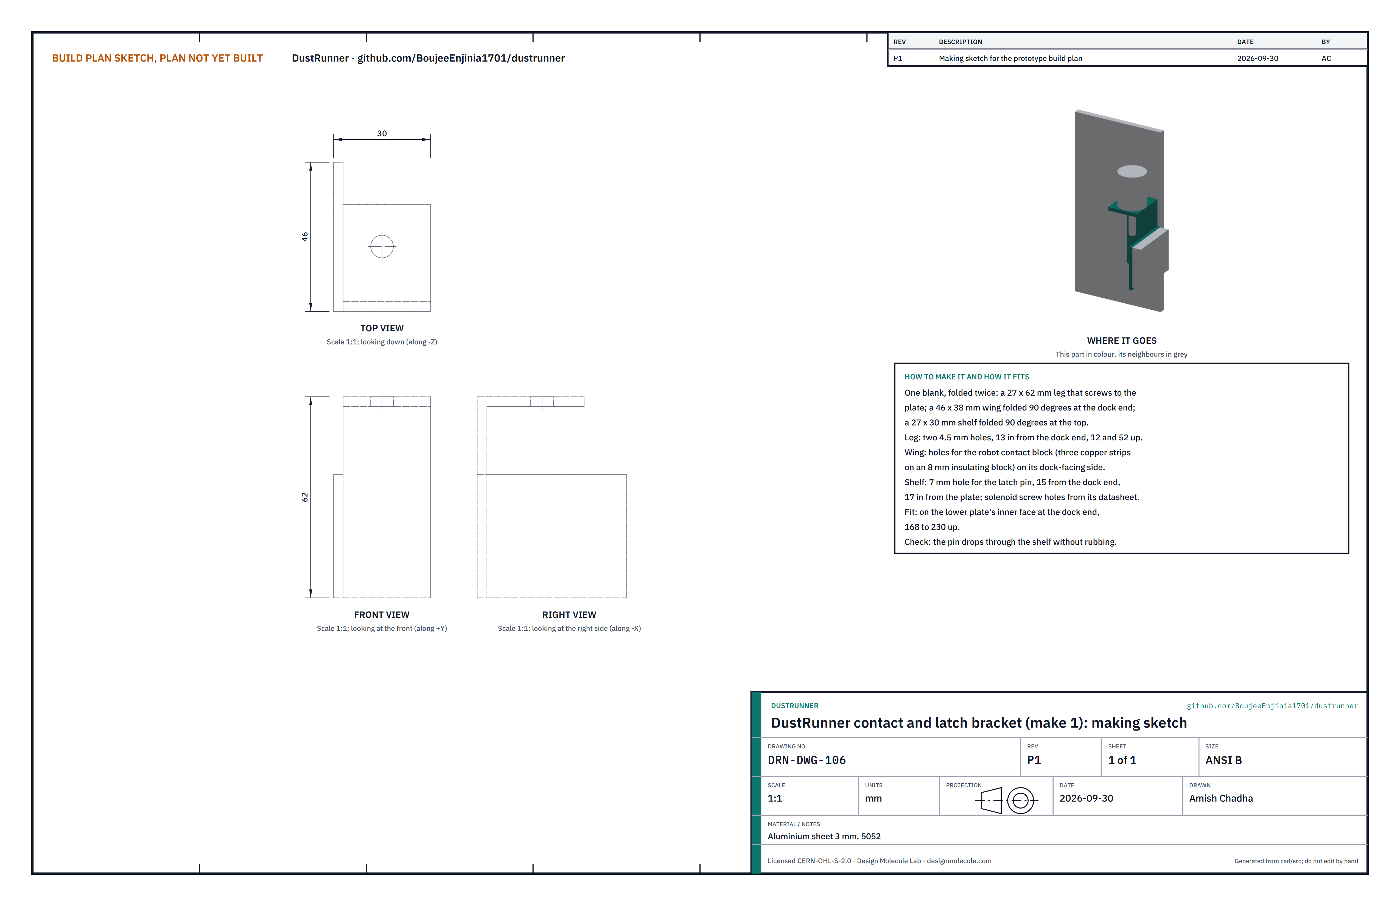
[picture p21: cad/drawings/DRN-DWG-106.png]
Figure 11. Making sketch of the contact and latch bracket


*Figure 11. Contact and latch bracket making sketch (DRN-DWG-106).*

**What it is and what it is made from.** A twice-folded bracket at the dock end of the lower plate that carries the robot's contact block and the latch solenoid. Aluminium sheet 3 mm, 5052.

**How to make it.**

1. Mark one blank: a 27 x 62 leg; a 46 x 38 wing on the dock end of the leg; a 27 x 30 shelf on its top. Fold the wing 90° inward and the shelf 90° inward.
2. Leg: two 4.5 mm holes, 13 from the dock end, 12 and 52 up from its bottom edge.
3. Shelf: a 7 mm hole for the latch pin, 15 from the dock end and 17 in from the plate; the solenoid's screw holes from its datasheet.
4. Wing: holes for the robot contact block (an 8 mm insulating block of HDPE or PTFE carrying three copper strips) on its dock-facing side.

**How it fits the parts next to it.** The leg screws to the lower plate's inner face at the dock end, 168 to 230 up. The contact block faces the dock; the solenoid stands on the shelf with its 6 mm pin pointing down through the hole. When the robot parks, the pin drops through the dock's latch tab (Figure 30).

**Check before moving on.** The pin drops through the shelf hole without rubbing when the solenoid is off and lifts clear when it is energised from a 12 V bench supply.

### 3.7 Chassis beam (make 1)

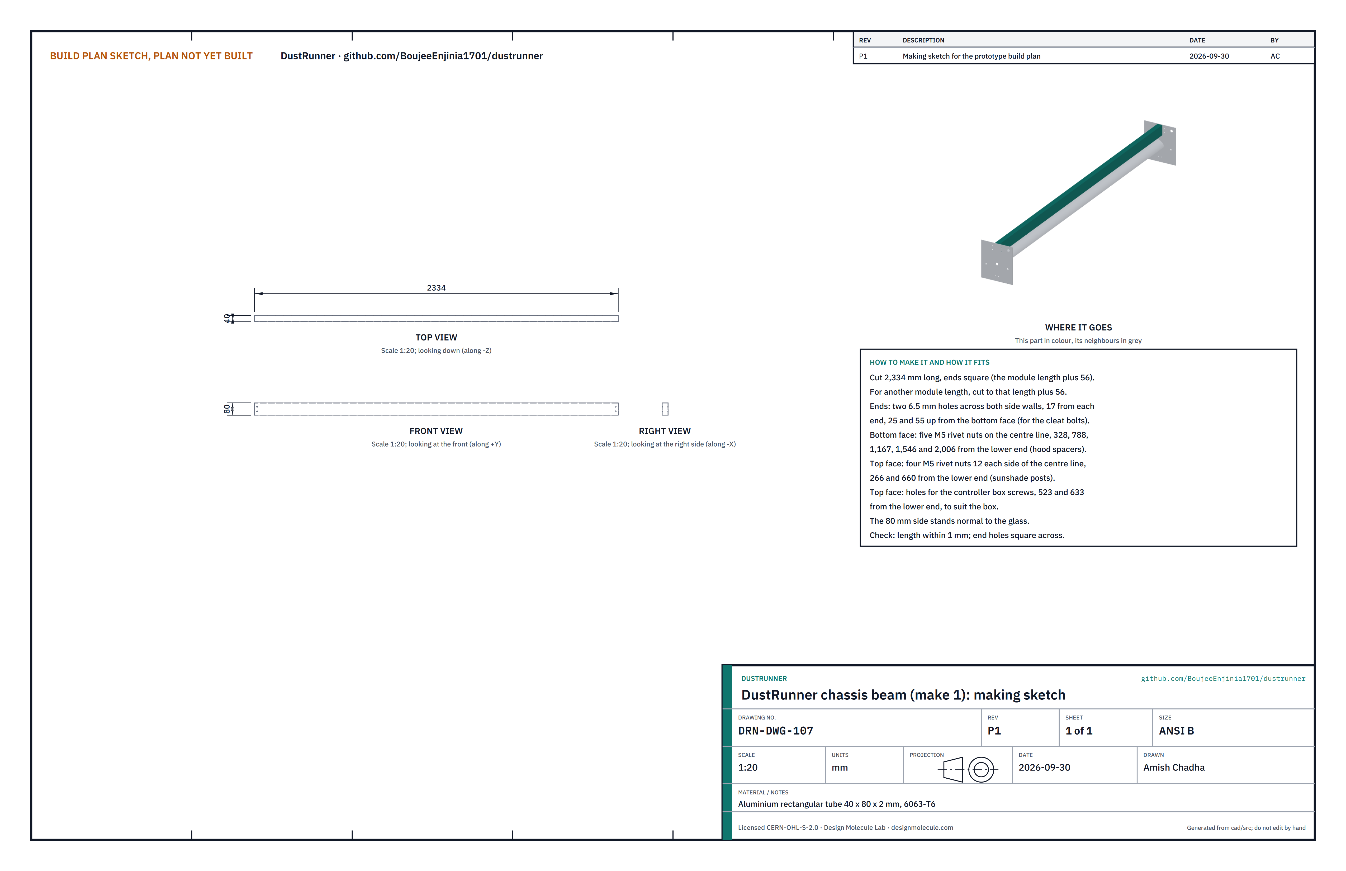
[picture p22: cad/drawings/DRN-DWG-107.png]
Figure 12. Making sketch of the chassis beam


*Figure 12. Chassis beam making sketch (DRN-DWG-107).*

**What it is and what it is made from.** The backbone that spans between the trucks and carries the hood, pack, controller and sunshade. Aluminium rectangular tube 40 x 80 x 2 mm, 6063-T6.

**How to make it.**

1. Cut 2,334 long with square ends (the module length plus 56; for another module length, cut that length plus 56).
2. At each end, two 6.5 mm holes across both side walls, 17 from the end, 25 and 55 up from the bottom face.
3. Bottom face: five M5 rivet nuts on the centre line, 328, 788, 1,167, 1,546 and 2,006 from the lower end, for the hood spacers.
4. Top face: four M5 rivet nuts, 12 each side of the centre line, 266 and 660 from the lower end, for the sunshade posts; and holes for the controller box screws, about 523 and 633 from the lower end, to suit the box.

**How it fits the parts next to it.**

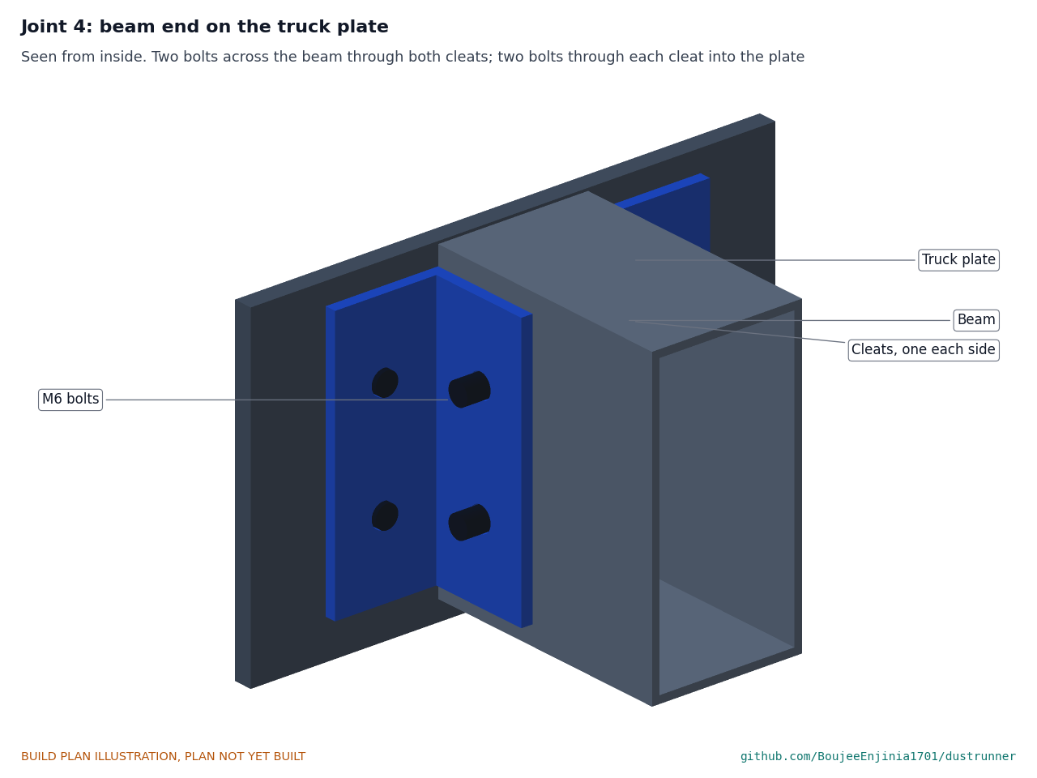
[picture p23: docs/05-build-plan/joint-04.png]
Figure 13. Joint 4: beam end on the truck plate


*Figure 13. Seen from inside: a cleat each side of the beam end, through-bolted across the beam and bolted to the plate.*

The 80 mm side stands normal to the glass; the beam's ends sit square against the plates' inner faces, its bottom face 3 mm above the hood.

**Check before moving on.** Length within 1 mm; the end holes are square across the tube.

### 3.8 Beam end cleats (make 4)

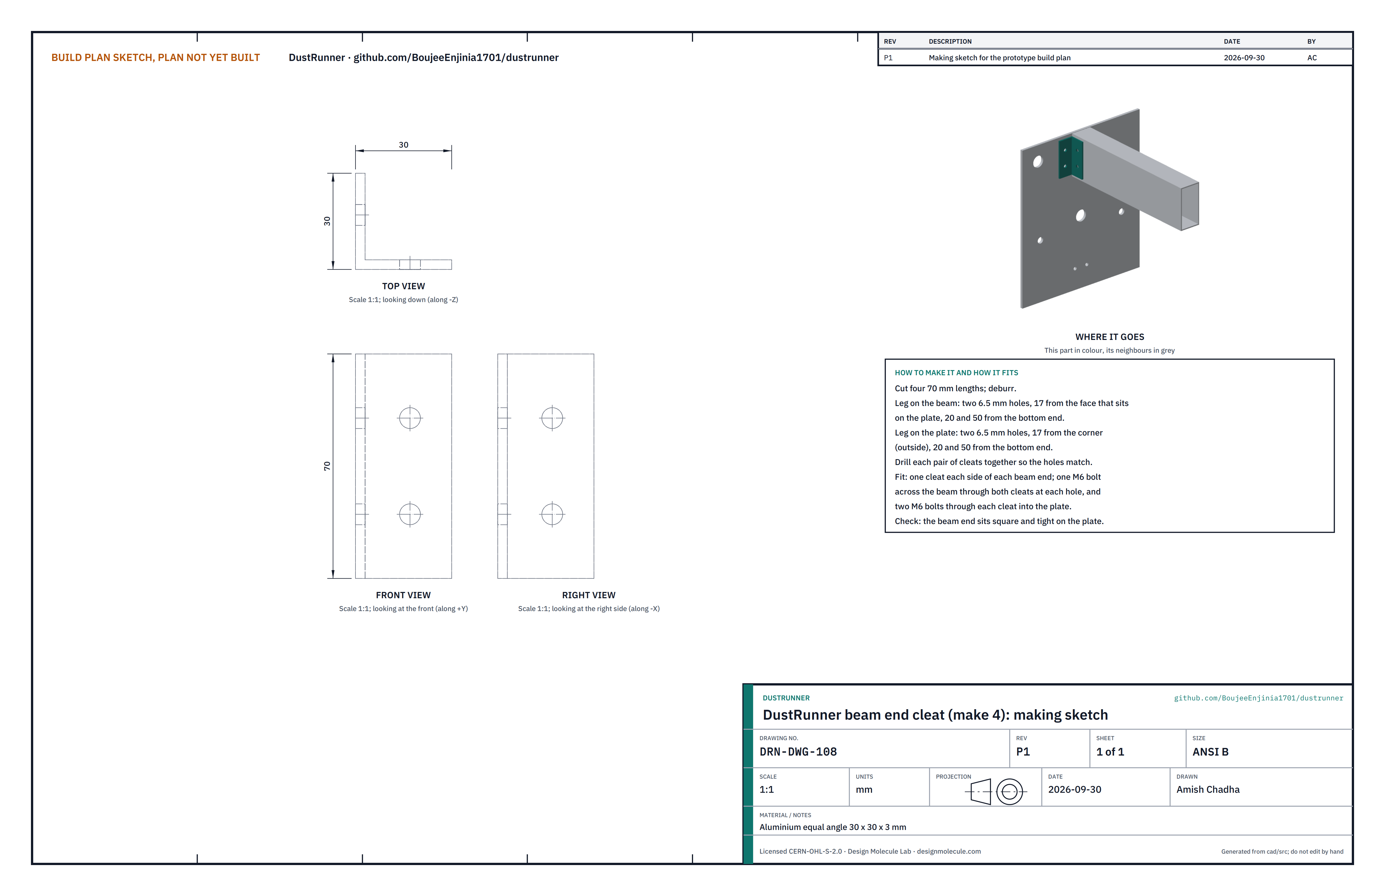
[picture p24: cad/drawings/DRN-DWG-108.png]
Figure 14. Making sketch of the beam end cleat


*Figure 14. Beam end cleat making sketch (DRN-DWG-108).*

**What it is and what it is made from.** A short angle each side of each beam end that bolts the beam to its truck plate. Aluminium equal angle 30 x 30 x 3 mm.

**How to make it.**

1. Cut four 70 mm lengths; deburr.
2. Leg on the beam: two 6.5 mm holes, 17 from the face that sits on the plate, 20 and 50 from the bottom end.
3. Leg on the plate: two 6.5 mm holes, 17 from the outside of the corner, 20 and 50 from the bottom end.
4. Drill each pair together so the holes match.

**How it fits the parts next to it.** One cleat each side of each beam end (Figure 13). One M6 bolt across the beam passes through both cleats at each hole, and two M6 bolts through each cleat go into the plate.

**Check before moving on.** The beam end sits square and tight on the plate with no gap.

### 3.9 Brush core, end plugs and stub shafts

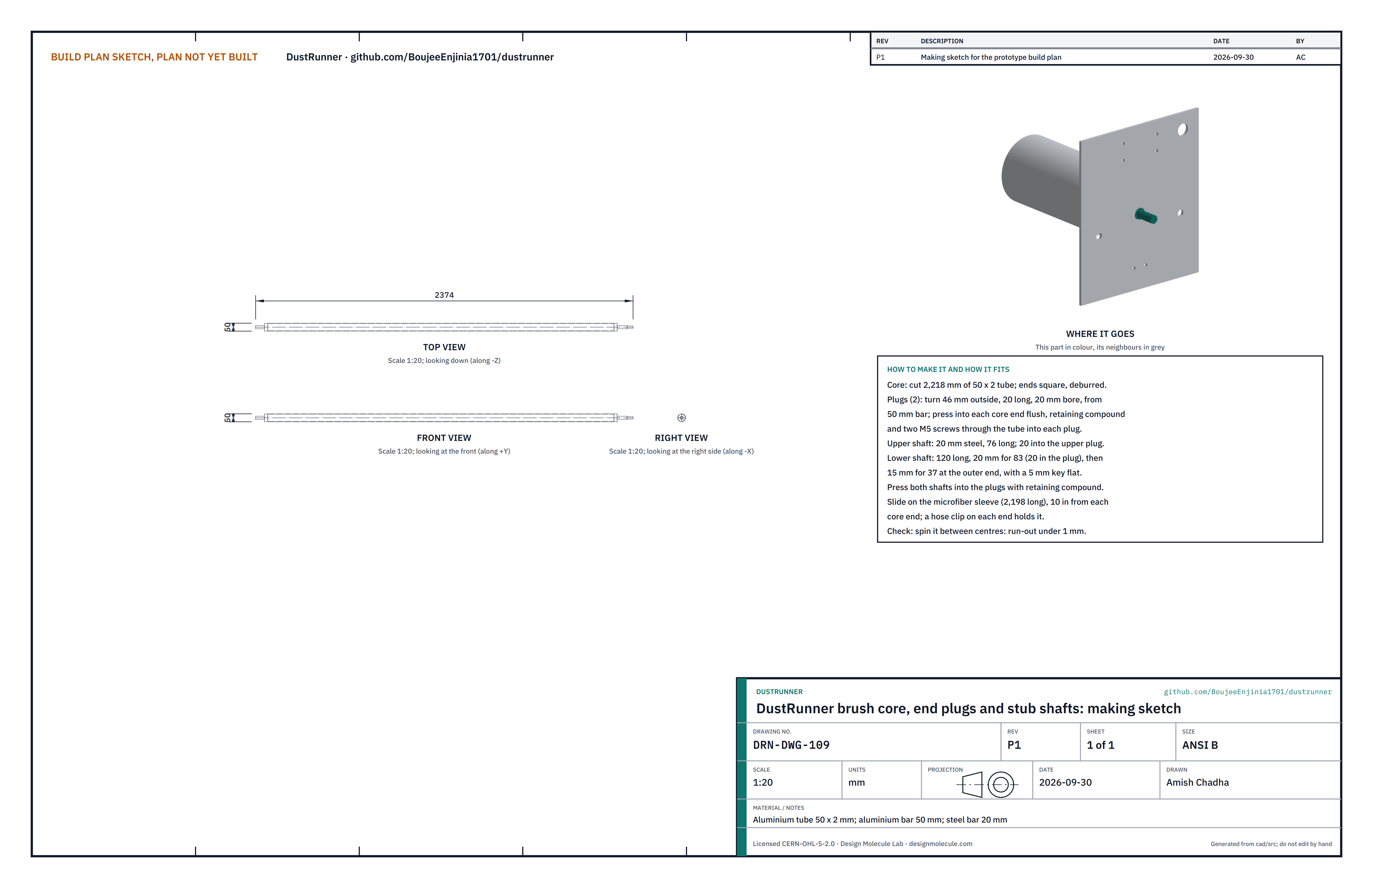
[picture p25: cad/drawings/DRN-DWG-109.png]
Figure 15. Making sketch of the brush core, plugs and shafts


*Figure 15. Brush core, plugs and shafts making sketch (DRN-DWG-109).*

**What it is and what it is made from.** The rotating core that carries the microfiber sleeve. Aluminium tube 50 x 2 mm (core); aluminium bar 50 mm (plugs); steel bar 20 mm (shafts). The plugs and the lower shaft are turned on a lathe (a local turning shop).

**How to make it.**

1. Core: cut 2,218 mm of tube; square and deburr the ends.
2. Plugs (2): turn 46 outside, 20 long, with a 20 mm bore. Press one flush into each core end with retaining compound and fix with two M5 screws through the tube.
3. Upper shaft: 20 mm steel, 76 long; press 20 into the upper plug.
4. Lower shaft: 120 long, 20 mm for 83 (20 of it in the plug), then turned to 15 mm for 37 at the outer end with a 5 mm key flat for the pulley. Press it into the lower plug.
5. Slide on the microfiber sleeve (2,198 long), 10 in from each core end; a hose clip at each end holds it.

**How it fits the parts next to it.**

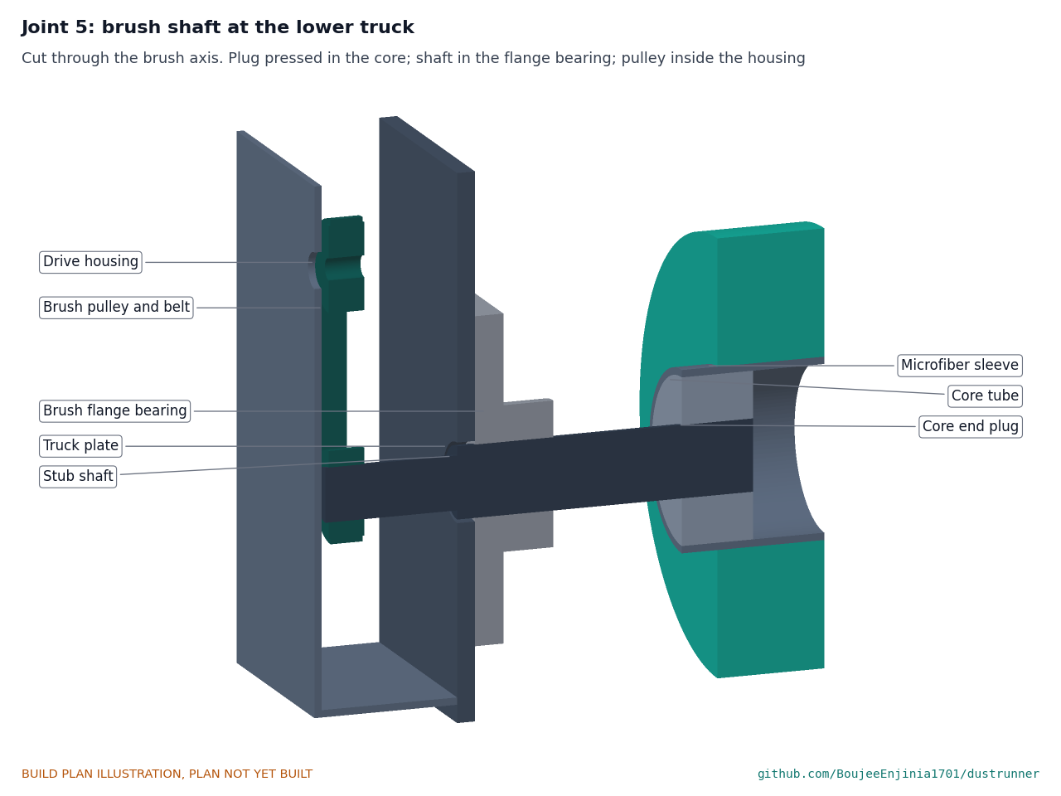
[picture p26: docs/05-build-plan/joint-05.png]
Figure 16. Joint 5: brush shaft at the lower truck


*Figure 16. Cut through the brush axis: plug in the core, shaft through the flange bearing and the plate, pulley and belt inside the drive housing.*

Each shaft runs in a 20 mm 2-bolt flange bearing on the plate's inner face. The lower shaft passes through the plate into the drive housing, where its pulley sits in the second belt layer, 2.5 mm clear of the wheel belt. The brush axis sits 55.5 above the glass, so the 120 mm sleeve presses 4.5 mm into the glass plane at the bearings.

**Check before moving on.** Spun between centres, the core runs true within 1 mm.

### 3.10 Brush hood (make 1)

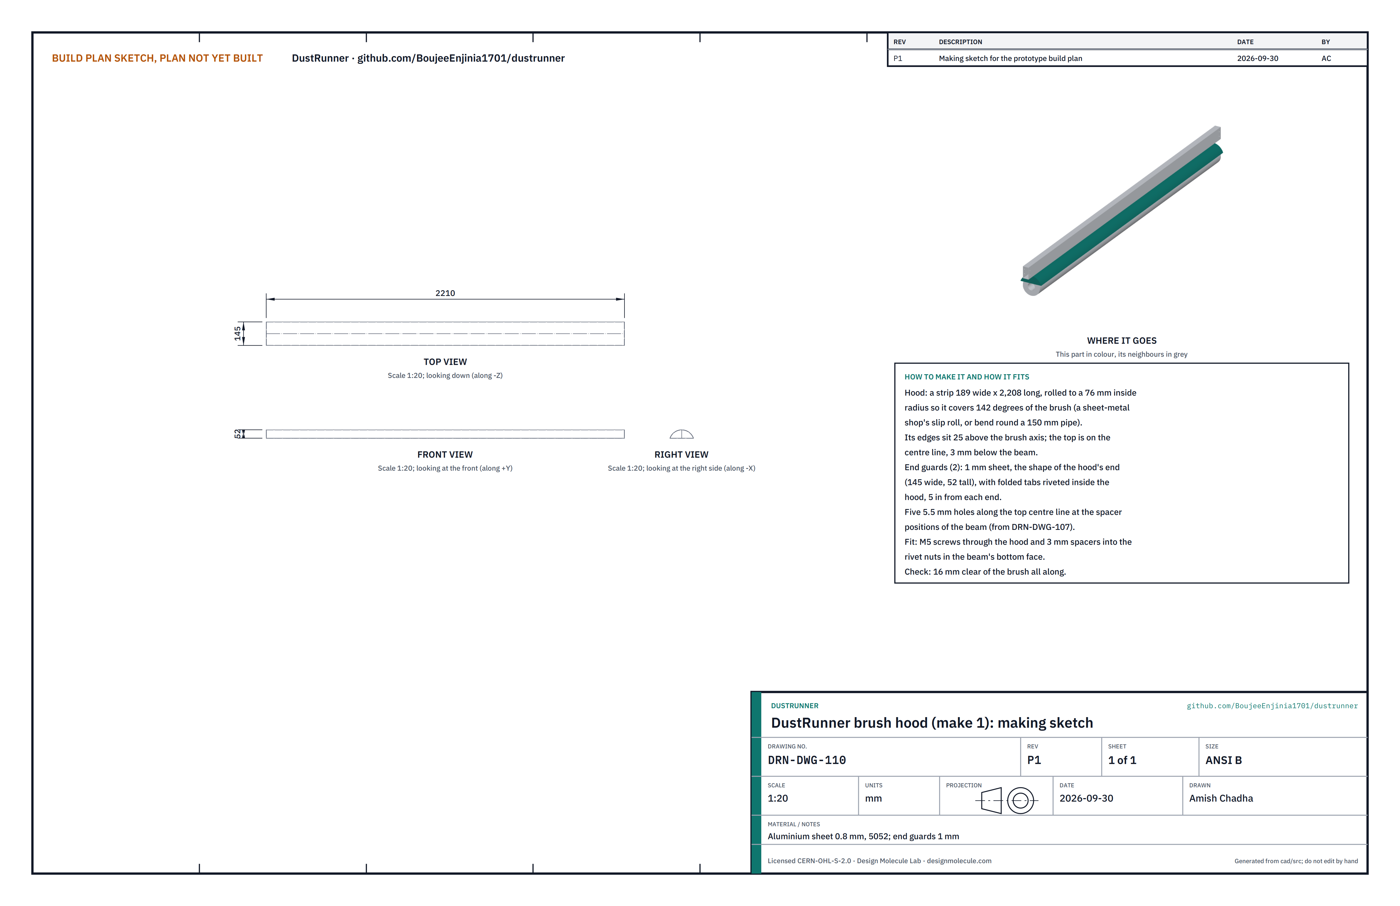
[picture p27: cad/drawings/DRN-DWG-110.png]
Figure 17. Making sketch of the brush hood


*Figure 17. Brush hood making sketch (DRN-DWG-110).*

**What it is and what it is made from.** A rolled cover over the top of the brush that keeps thrown dust off clean glass and guards the brush ends. Aluminium sheet 0.8 mm, 5052; end guards 1 mm.

**How to make it.**

1. Cut a strip 189 wide x 2,208 long. Roll it to a 76 mm inside radius on a sheet-metal shop's slip roll (or bend it round a 150 mm pipe) so it covers 142° of the brush.
2. End guards (2): 1 mm sheet, the shape of the hood's end (145 wide, 52 tall), with folded tabs; rivet one inside each end, 5 in from the end.
3. Drill five 5.5 mm holes along the top centre line at the beam's spacer positions (Section 3.7).

**How it fits the parts next to it.**

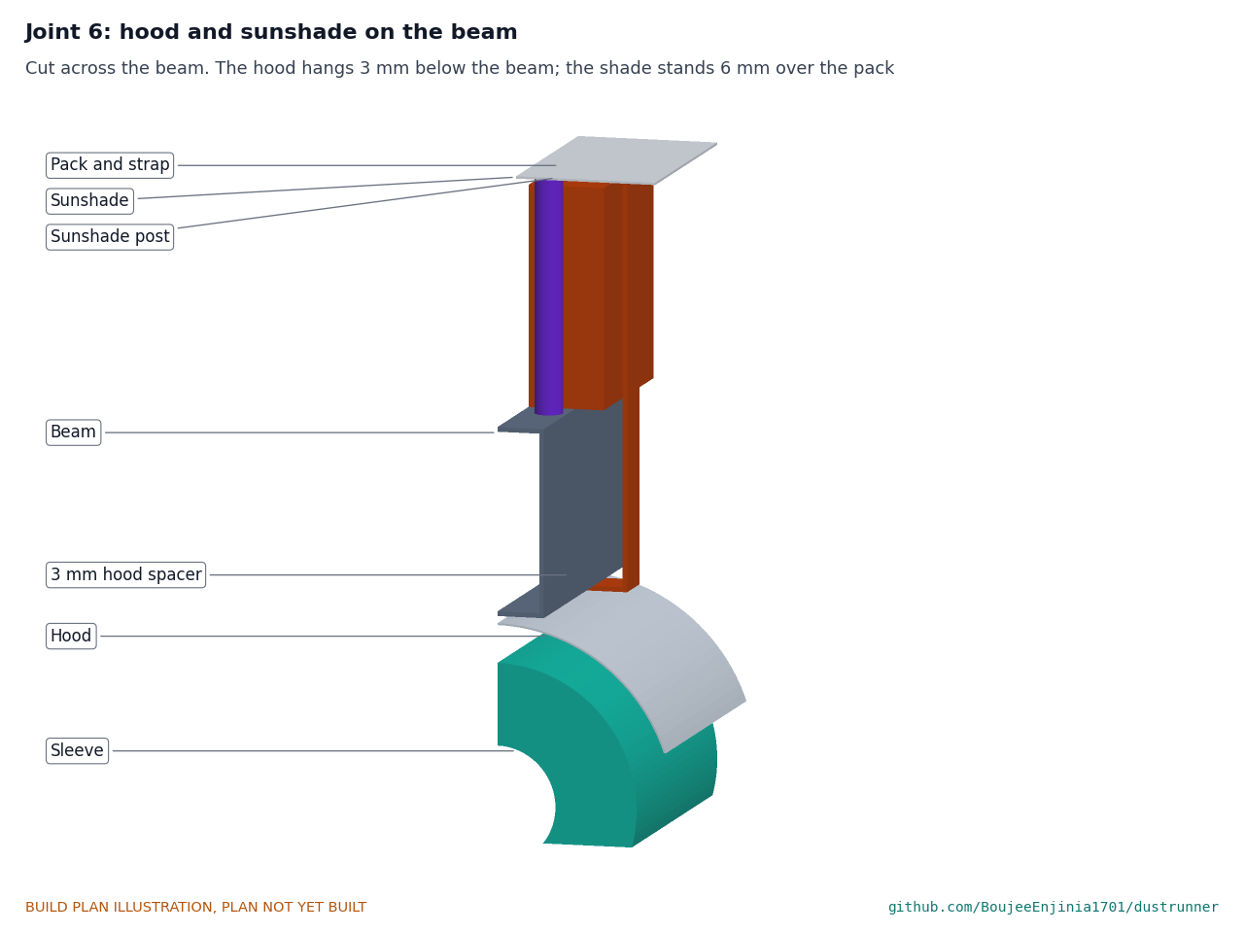
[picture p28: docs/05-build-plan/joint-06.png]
Figure 18. Joint 6: hood and sunshade on the beam


*Figure 18. Cut across the beam: the hood hangs on 3 mm spacers below the beam; the sunshade stands on posts 6 mm over the pack.*

M5 screws pass up through the hood and a 3 mm nylon spacer into the rivet nuts in the beam's bottom face. The hood's edges sit 25 above the brush axis and its inside is 16 mm clear of the brush all along.

**Check before moving on.** Turn the brush by hand: nothing touches.

### 3.11 Sunshade and posts

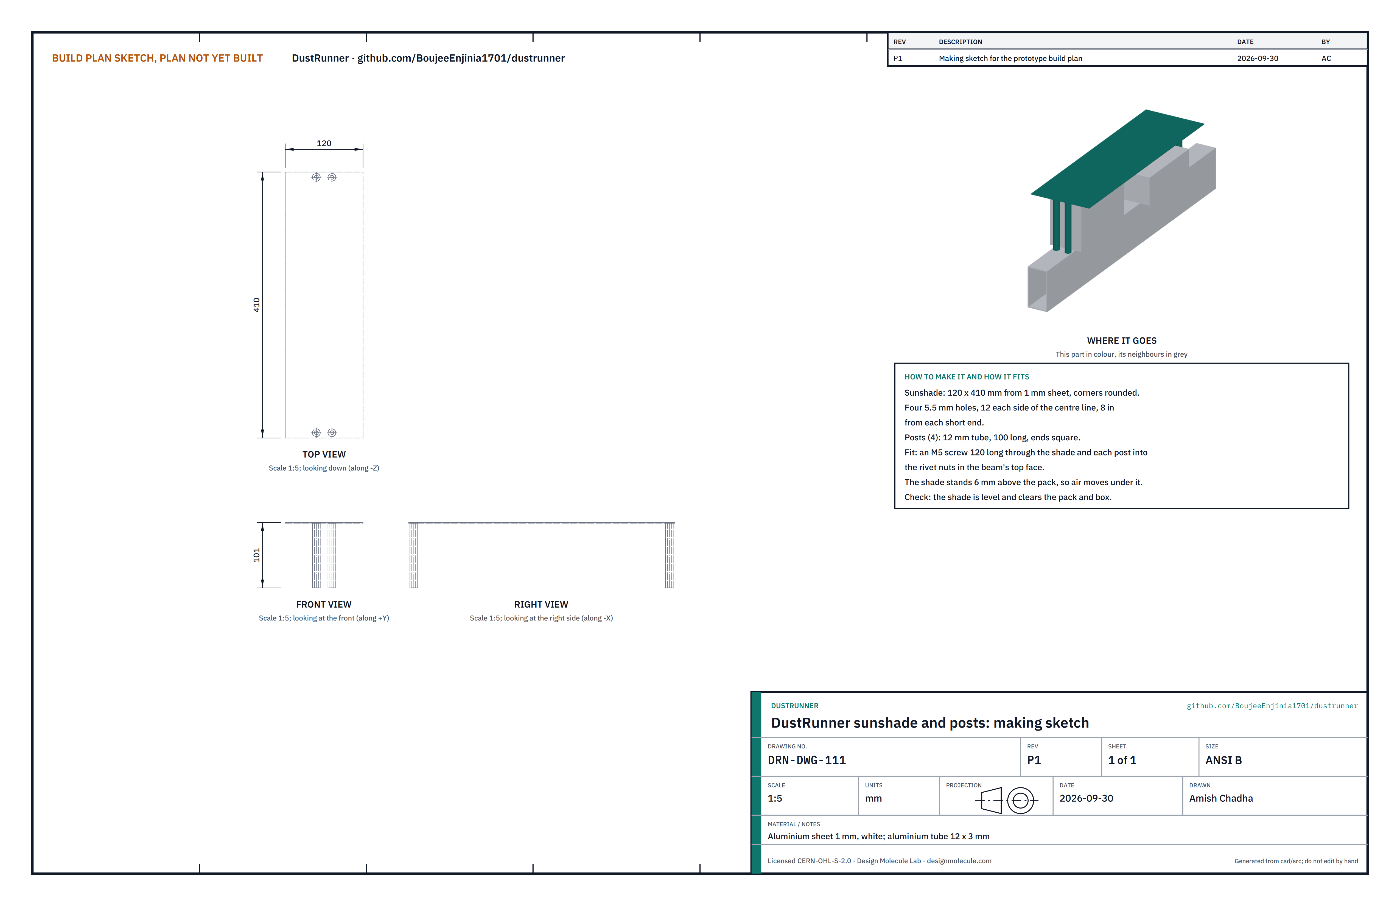
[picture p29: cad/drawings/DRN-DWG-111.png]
Figure 19. Making sketch of the sunshade and posts


*Figure 19. Sunshade and posts making sketch (DRN-DWG-111).*

**What it is and what it is made from.** A sheet that shades the pack and controller. Aluminium sheet 1 mm, white; aluminium tube 12 x 3 mm for the posts.

**How to make it.**

1. Cut the shade 120 x 410; round the corners. Drill four 5.5 mm holes, 12 each side of the centre line, 8 in from each short end.
2. Cut four posts from 12 mm tube, 100 long, ends square.

**How it fits the parts next to it.** An M5 screw 120 long passes through the shade and each post into a rivet nut in the beam's top face (Figure 18). The shade stands 6 mm above the pack so air can move under it.

**Check before moving on.** The shade is level and clears the pack and the controller box.

### 3.12 Dock rails (make 2)

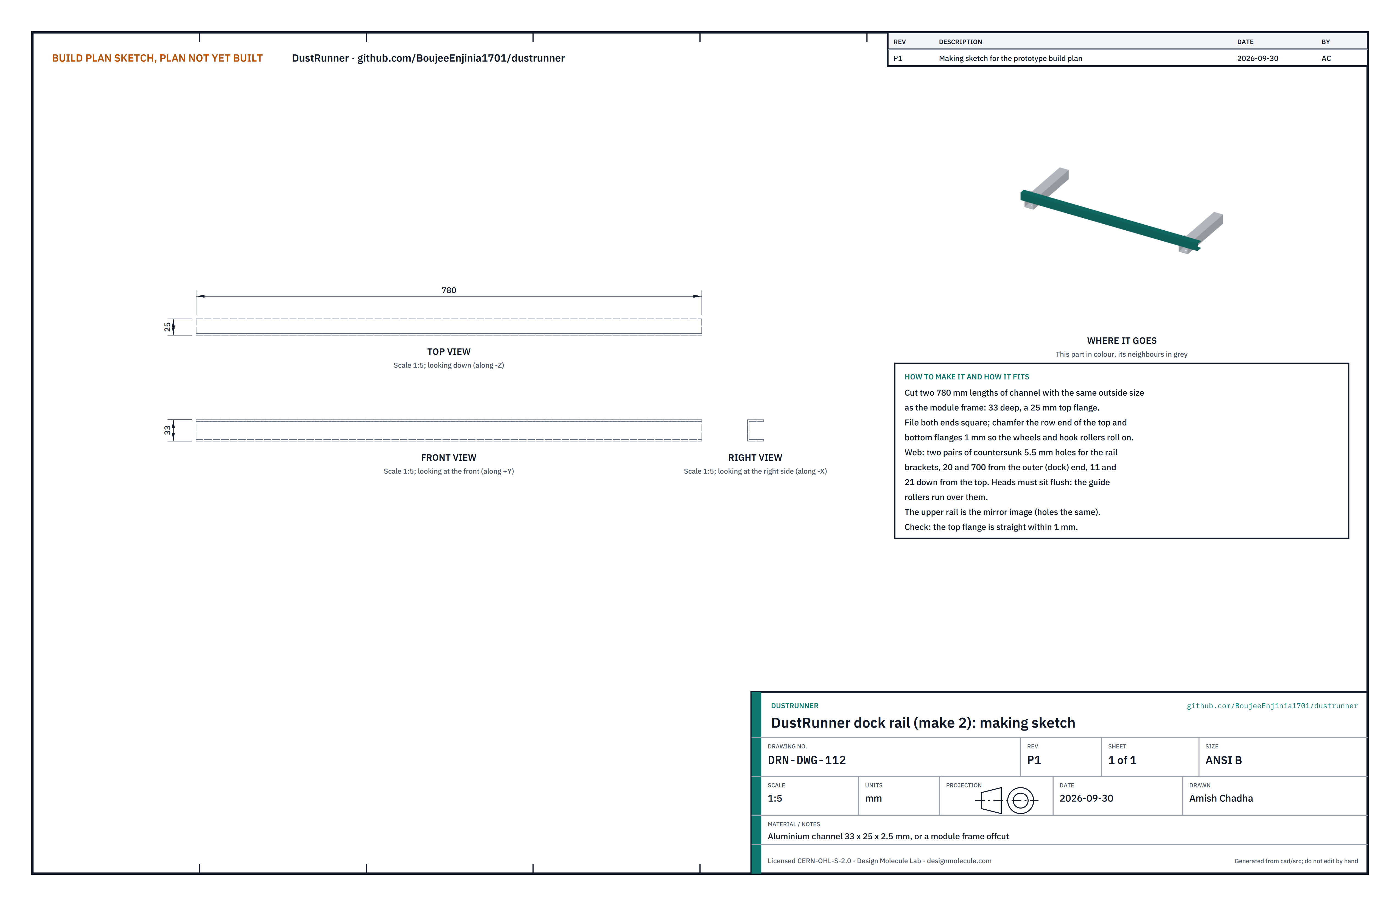
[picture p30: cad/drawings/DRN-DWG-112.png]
Figure 20. Making sketch of the dock rail


*Figure 20. Dock rail making sketch (DRN-DWG-112).*

**What it is and what it is made from.** The two short rails the robot parks on, continuing the module frame's profile past the end of the row. Aluminium channel 33 x 25 x 2.5 mm, or an offcut of the same module frame.

**How to make it.**

1. Cut two 780 mm lengths of channel the same outside size as the module frame: 33 deep with a 25 mm top flange.
2. File both ends square; chamfer the row end of the top and bottom flanges 1 mm so the wheels and hook rollers roll on.
3. Web: two pairs of countersunk 5.5 mm holes, 20 and 700 from the outer (dock) end, 11 and 21 down from the top. The heads must sit flush, because the guide rollers run over them.

**How it fits the parts next to it.** Each rail lies in line with the module frame, its top level with the frame top and its outer face in line with the frame's outer face, with the same 20 mm gap as between modules. It sits on two rail brackets (Section 3.14).

**Check before moving on.** The top flange is straight within 1 mm.

### 3.13 Dock cross members (make 3)

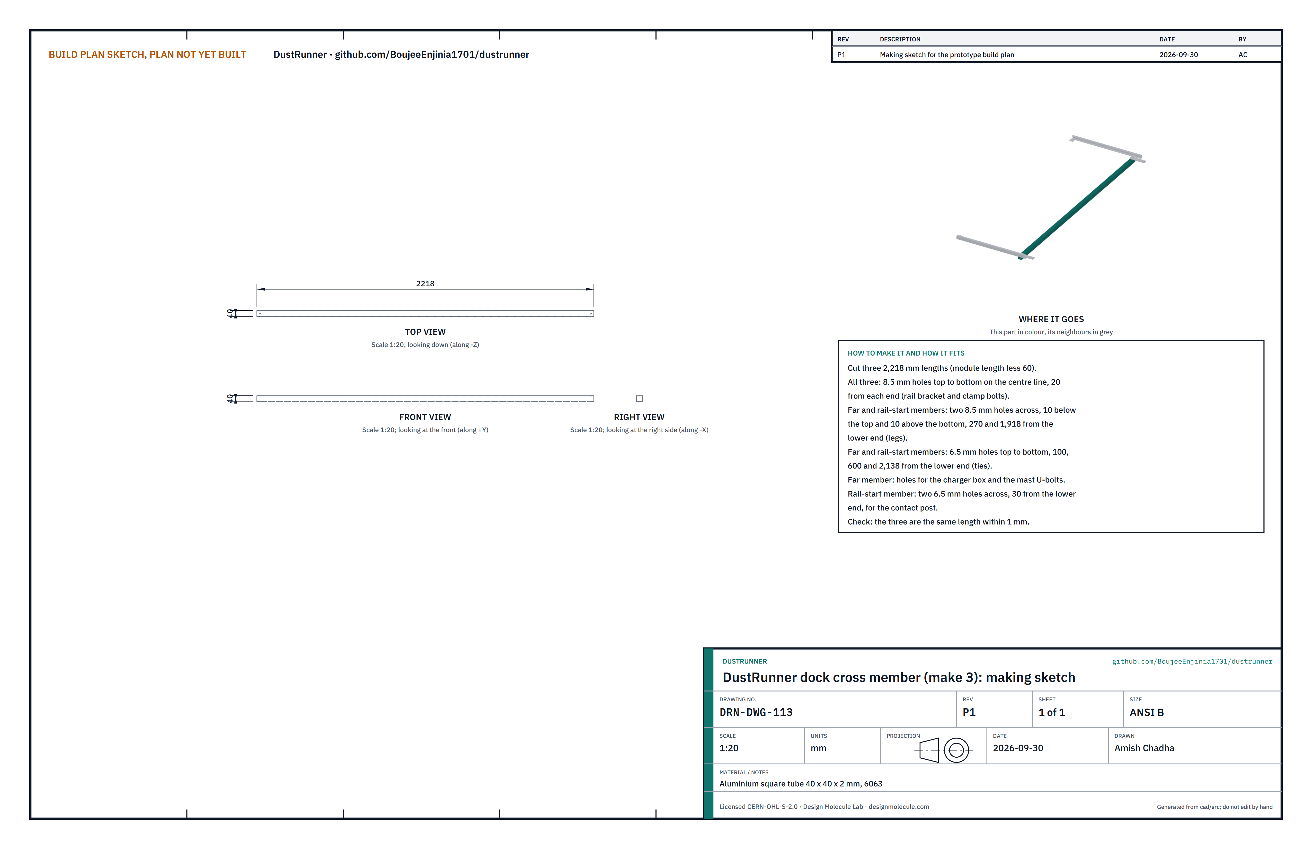
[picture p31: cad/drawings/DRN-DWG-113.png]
Figure 21. Making sketch of the dock cross member


*Figure 21. Dock cross member making sketch (DRN-DWG-113).*

**What it is and what it is made from.** The three members across the slope that make the dock frame: the far member (panel end), the rail-start member and the near member (next to the first module). Aluminium square tube 40 x 40 x 2 mm, 6063.

**How to make it.**

1. Cut three 2,218 mm lengths (the module length less 60).
2. All three: 8.5 mm holes top to bottom on the centre line, 20 from each end.
3. Far and rail-start members: two 8.5 mm holes across, 10 below the top and 10 above the bottom, 270 and 1,918 from the lower end, for the legs; and 6.5 mm holes top to bottom 100, 600 and 2,138 from the lower end, for the ties.
4. Far member: holes for the charger box and the two mast U-bolts. Rail-start member: two 6.5 mm holes across, 30 from the lower end, for the contact post.

**How it fits the parts next to it.**

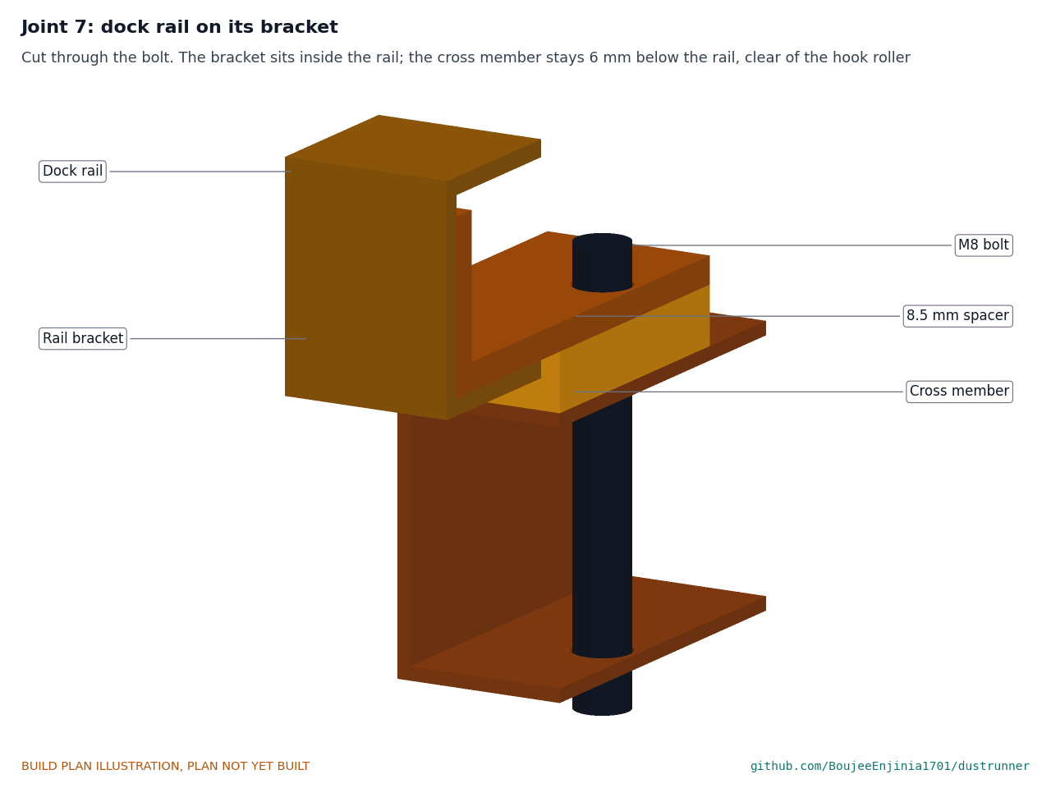
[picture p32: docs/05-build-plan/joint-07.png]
Figure 22. Joint 7: dock rail on its bracket


*Figure 22. Cut through the bolt: the bracket inside the rail, the spacer, and the cross member 6 mm below the rail.*

Each member's top is 6 mm below the rail's bottom flange and its end 30 mm inside the rail, so the robot's hook roller, which runs under the rail, never meets it.

**Check before moving on.** The three members are the same length within 1 mm.

### 3.14 Rail brackets (make 4), spacers and shims

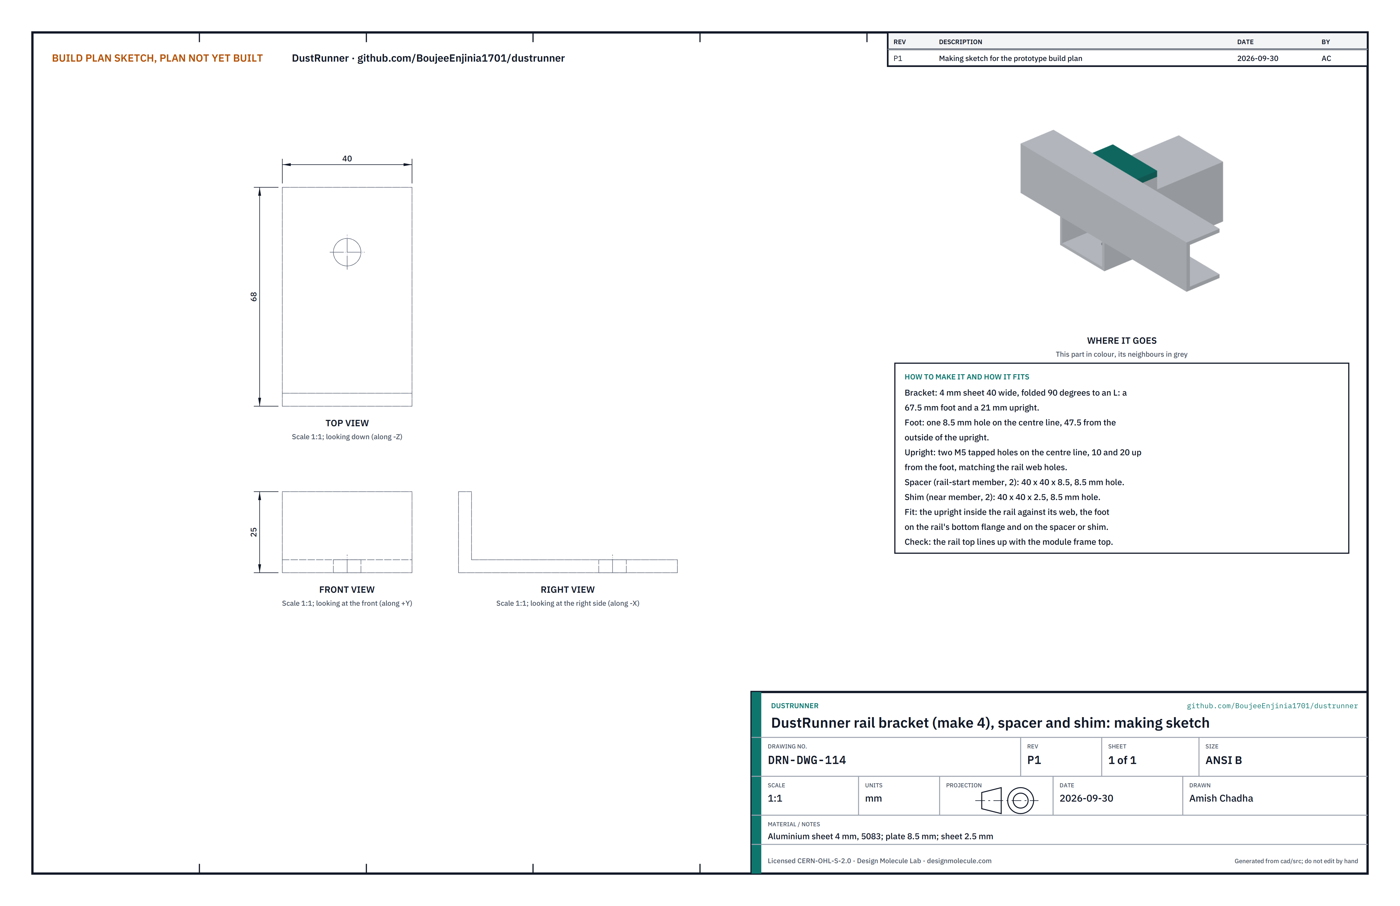
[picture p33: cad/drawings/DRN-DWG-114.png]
Figure 23. Making sketch of the rail bracket


*Figure 23. Rail bracket, spacer and shim making sketch (DRN-DWG-114).*

**What it is and what it is made from.** The brackets that hold each rail from inside its channel. Aluminium sheet 4 mm, 5083; spacers from 8.5 mm plate; shims from 2.5 mm sheet.

**How to make it.**

1. Brackets: 4 mm sheet 40 wide, folded 90° to an L with a 67.5 mm foot and a 21 mm upright.
2. Foot: one 8.5 mm hole on the centre line, 47.5 from the outside of the upright.
3. Upright: two M5 tapped holes on the centre line, 10 and 20 up from the foot, to match the rail web holes.
4. Spacers (2, for the rail-start member): 40 x 40 x 8.5 with an 8.5 mm hole. Shims (2, for the near member): 40 x 40 x 2.5 with an 8.5 mm hole.

**How it fits the parts next to it.** The upright stands inside the rail against its web, held by two countersunk M5 screws through the web; the foot lies on the inside of the rail's bottom flange and runs out of the channel onto the spacer (rail-start member) or onto the shim on the clamp bar (near member). One M8 bolt goes down through foot, spacer or shim and clamp bar, and the cross member (Figure 22). Add shims under the foot until the rail top is level with the module frame top.

**Check before moving on.** The rail top lines up with the module frame top within 1 mm.

### 3.15 Frame clamps (make 2)

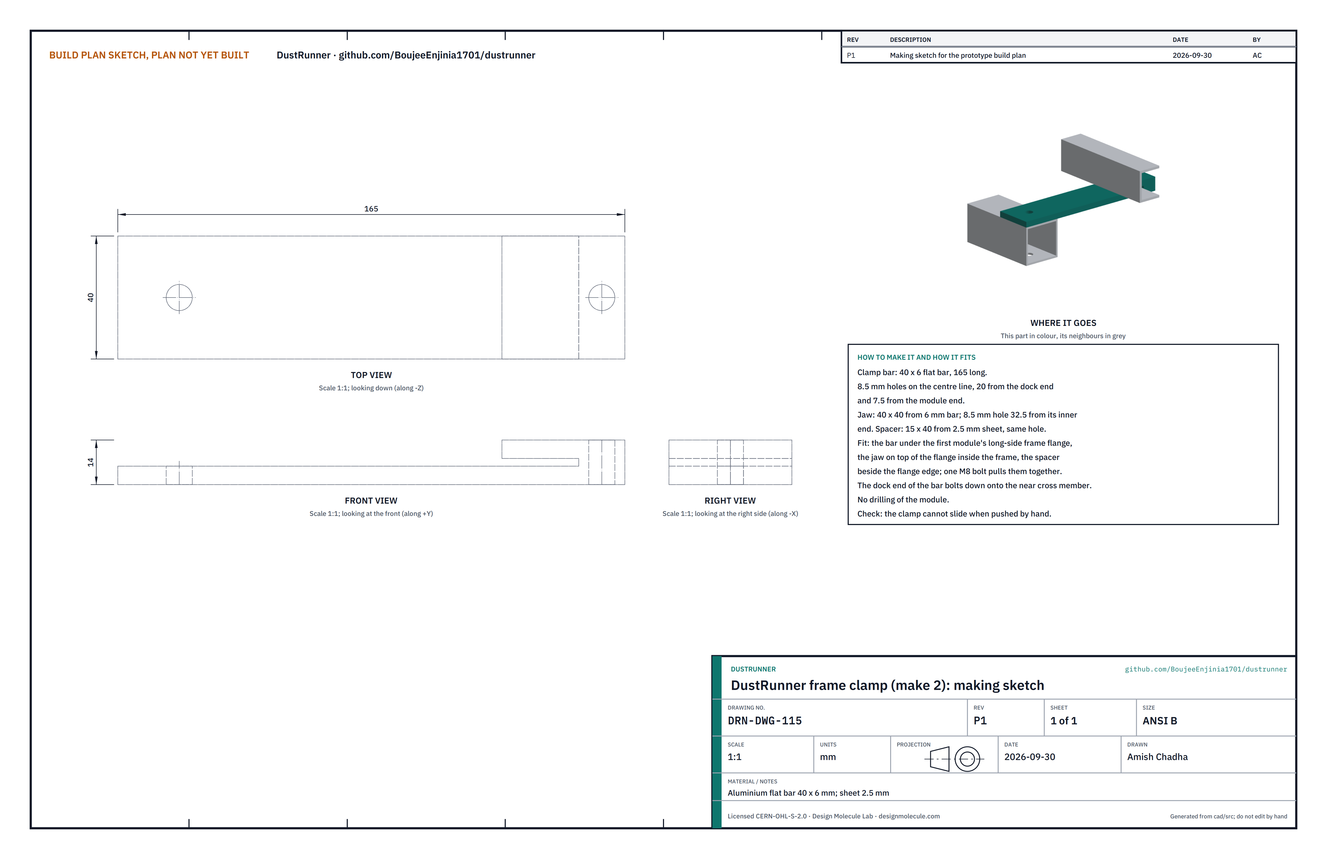
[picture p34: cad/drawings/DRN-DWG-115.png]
Figure 24. Making sketch of the frame clamp


*Figure 24. Frame clamp making sketch (DRN-DWG-115).*

**What it is and what it is made from.** The clamps that hold the dock to the first module's frame without drilling it. Aluminium flat bar 40 x 6 mm; sheet 2.5 mm.

**How to make it.**

1. Clamp bar: 40 x 6 flat bar, 165 long. 8.5 mm holes on the centre line, 20 from the dock end and 7.5 from the module end.
2. Jaw: 40 x 40 from 6 mm bar, with an 8.5 mm hole 32.5 from its inner end.
3. Spacer: 15 x 40 from 2.5 mm sheet, with an 8.5 mm hole to match.

**How it fits the parts next to it.**

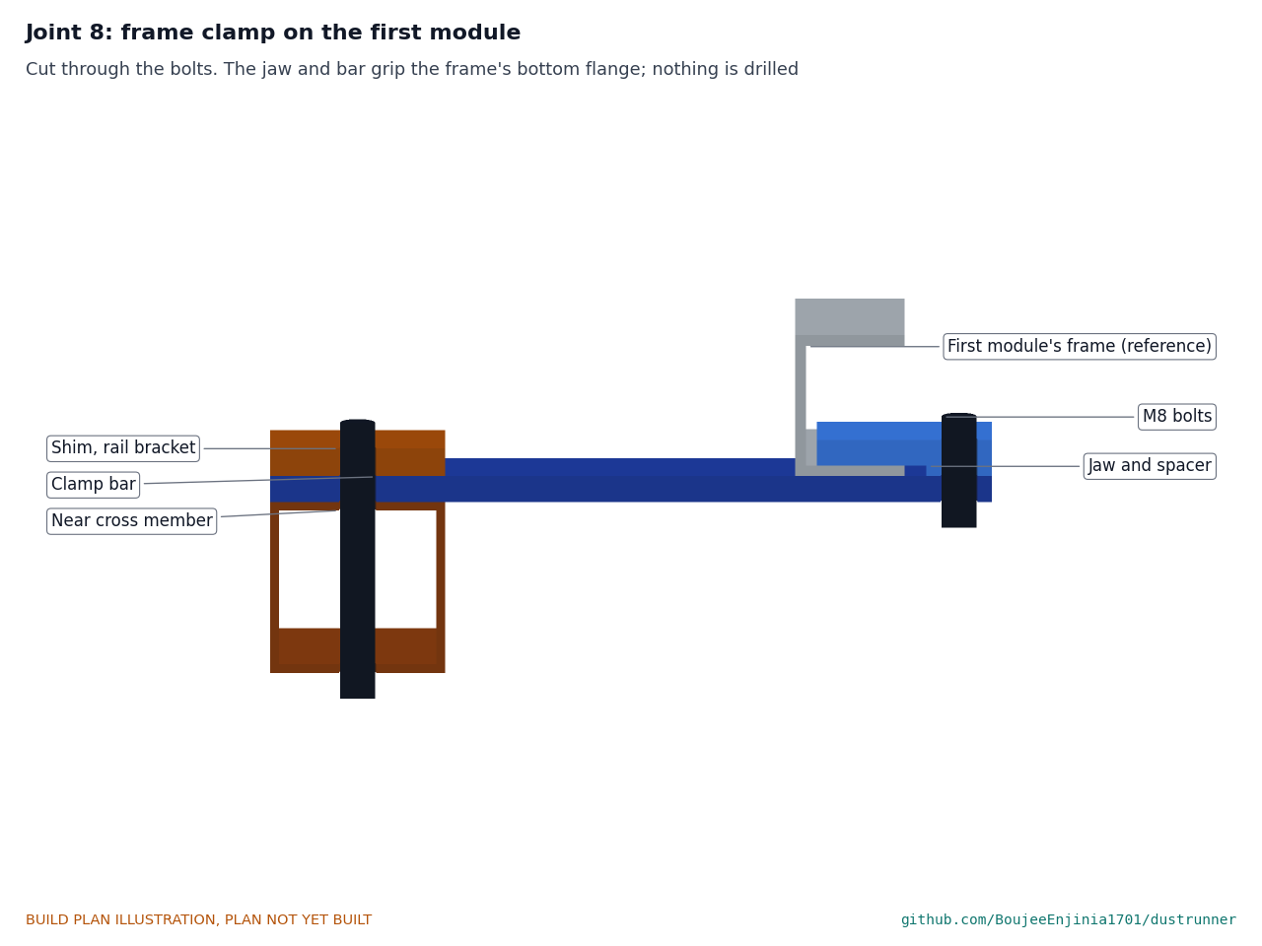
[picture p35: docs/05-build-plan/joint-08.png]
Figure 25. Joint 8: frame clamp on the first module


*Figure 25. Cut through the bolts: the bar under the frame's bottom flange, the jaw on top of it inside the frame, one M8 bolt; the bar's dock end bolted to the near cross member.*

The bar lies under the first module's long-side frame flange, 30 to 70 in from the module's lower and upper corners, clear of the table's own clamps. The jaw lies on top of the flange inside the frame, the spacer beside the flange edge keeps the jaw level, and one M8 bolt pulls jaw and bar together.

**Check before moving on.** The clamp cannot be slid along the frame by hand.

### 3.16 Dock ties (make 3)

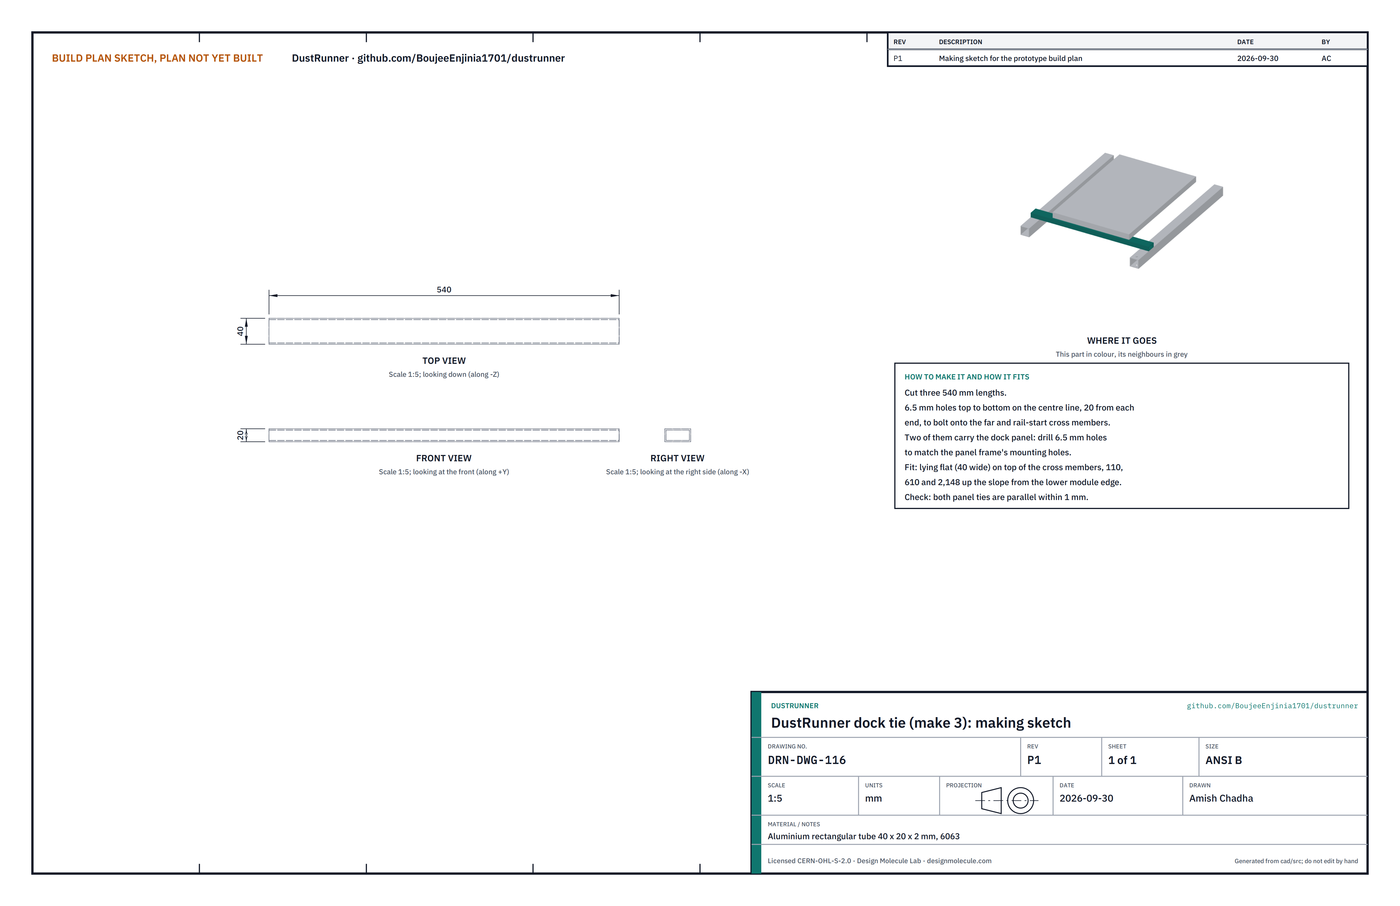
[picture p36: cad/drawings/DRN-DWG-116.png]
Figure 26. Making sketch of the dock tie


*Figure 26. Dock tie making sketch (DRN-DWG-116).*

**What it is and what it is made from.** Three members along the row that join the far and rail-start cross members; two carry the dock panel. Aluminium rectangular tube 40 x 20 x 2 mm, 6063.

**How to make it.**

1. Cut three 540 mm lengths.
2. 6.5 mm holes top to bottom on the centre line, 20 from each end.
3. On two of them, 6.5 mm holes to match the panel frame's mounting holes.

**How it fits the parts next to it.** The ties lie flat (40 wide) on top of the two cross members, 110, 610 and 2,148 up the slope from the lower module edge, bolted with M6 bolts. The panel bolts through its frame holes to the first two.

**Check before moving on.** The two panel ties are parallel within 1 mm.

### 3.17 Dock legs with foot plates (make 4)

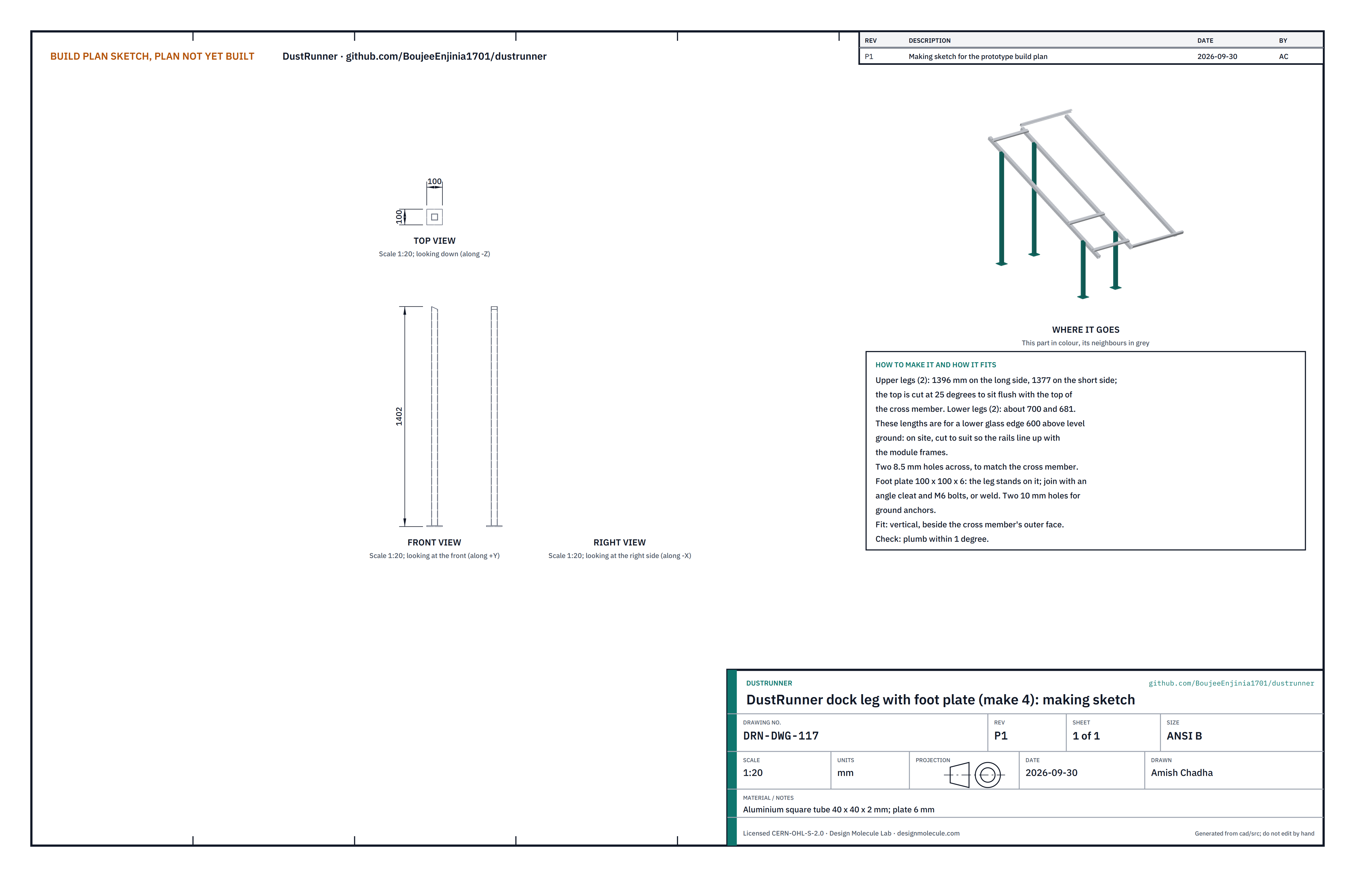
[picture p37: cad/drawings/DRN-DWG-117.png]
Figure 27. Making sketch of the dock leg


*Figure 27. Dock leg making sketch (DRN-DWG-117).*

**What it is and what it is made from.** Four vertical legs that carry the dock frame. Aluminium square tube 40 x 40 x 2 mm; plate 6 mm for the feet.

**How to make it.**

1. For a lower glass edge 600 above level ground: two upper legs 1,396 long on the long side and 1,377 on the short side, and two lower legs about 700 and 681; the top of each is cut at 25° so it sits flush with the top of the cross member. On site, cut to suit so the rails line up with the module frames.
2. Two 8.5 mm holes across, to match the cross member's leg holes.
3. Foot plate 100 x 100 x 6; join leg and foot with an angle cleat and M6 bolts (or weld); two 10 mm holes for ground anchors.

**How it fits the parts next to it.**

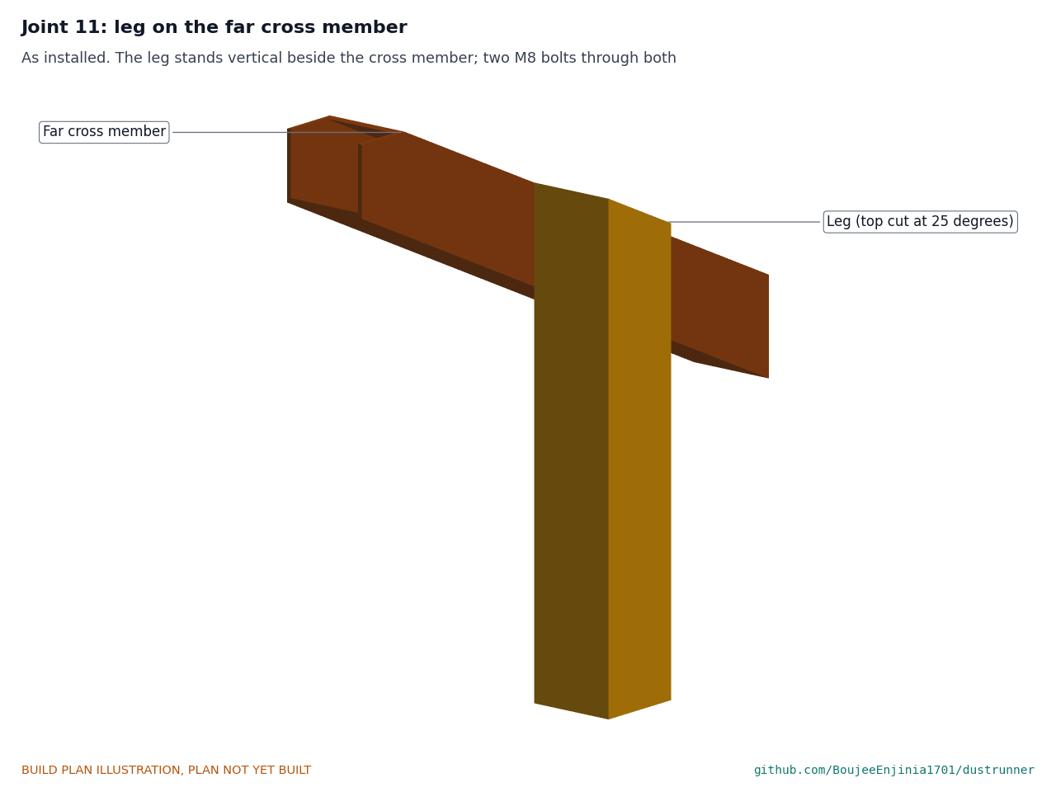
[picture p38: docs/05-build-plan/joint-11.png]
Figure 28. Joint 11: leg on the far cross member


*Figure 28. As installed: the leg stands vertical beside the cross member's outer face, bolted through both.*

**Check before moving on.** Each leg stands plumb within 1°.

### 3.18 Contact post, dock contacts and latch tab

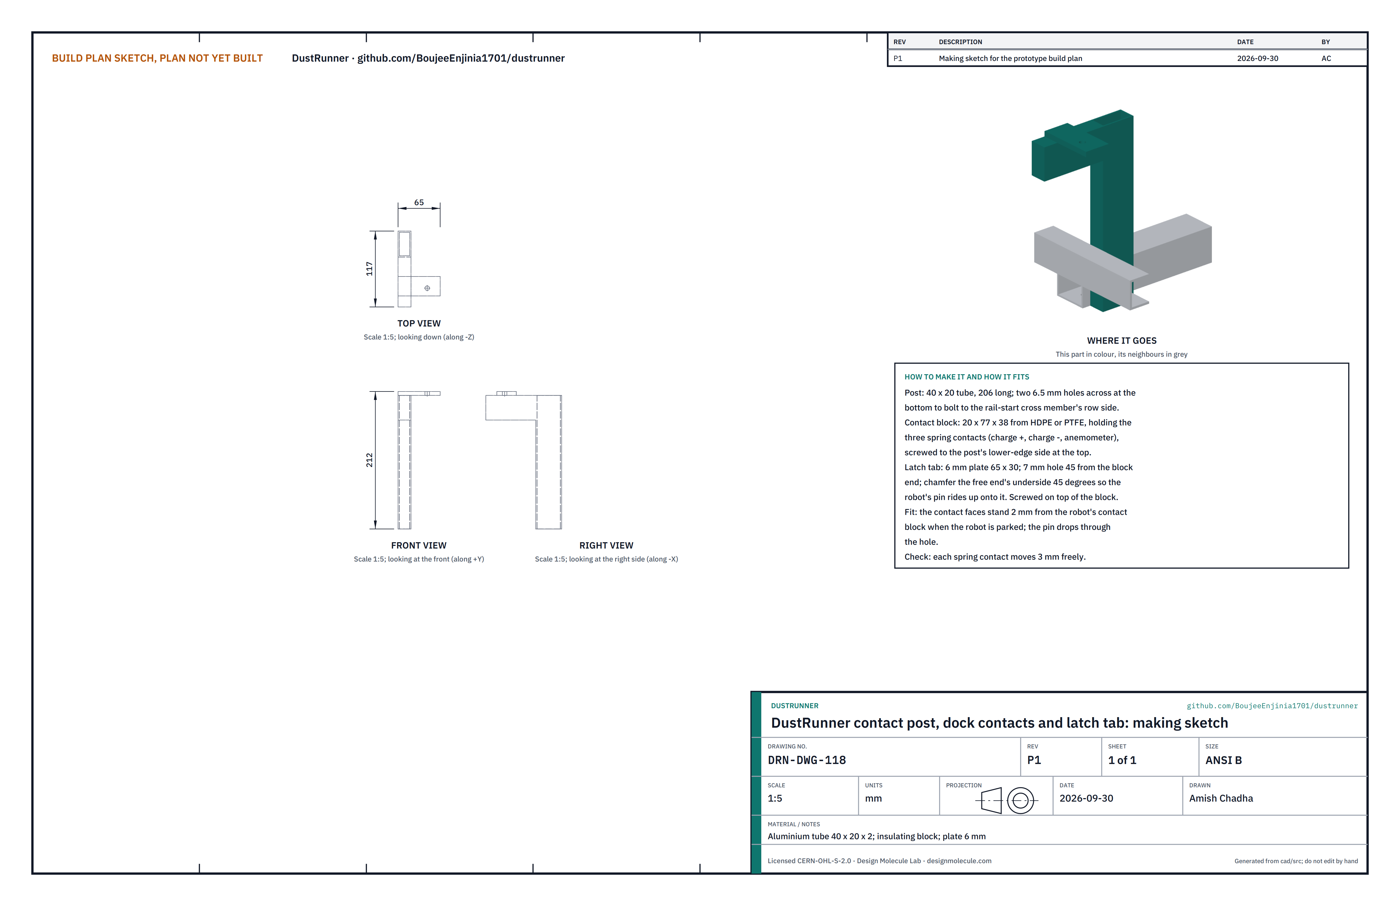
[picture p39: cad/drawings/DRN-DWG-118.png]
Figure 29. Making sketch of the contact post, dock contacts and latch tab


*Figure 29. Contact post, dock contacts and latch tab making sketch (DRN-DWG-118).*

**What it is and what it is made from.** The post at the rail start that carries the dock's contact block and the latch tab. Aluminium tube 40 x 20 x 2 mm (post); HDPE or PTFE (contact block); 6 mm aluminium plate (tab).

**How to make it.**

1. Post: cut 206 long; two 6.5 mm holes across at the bottom, to bolt to the rail-start cross member's row side.
2. Contact block: 20 x 77 x 38 of HDPE or PTFE, drilled for the three spring contacts (charge positive, charge negative, anemometer signal) and screwed to the post's lower side at the top.
3. Latch tab: 65 x 30 from 6 mm plate, with a 7 mm hole 45 from the block end; chamfer the underside of the free end 45° so the robot's pin rides up onto it. Screw it on top of the block.

**How it fits the parts next to it.**

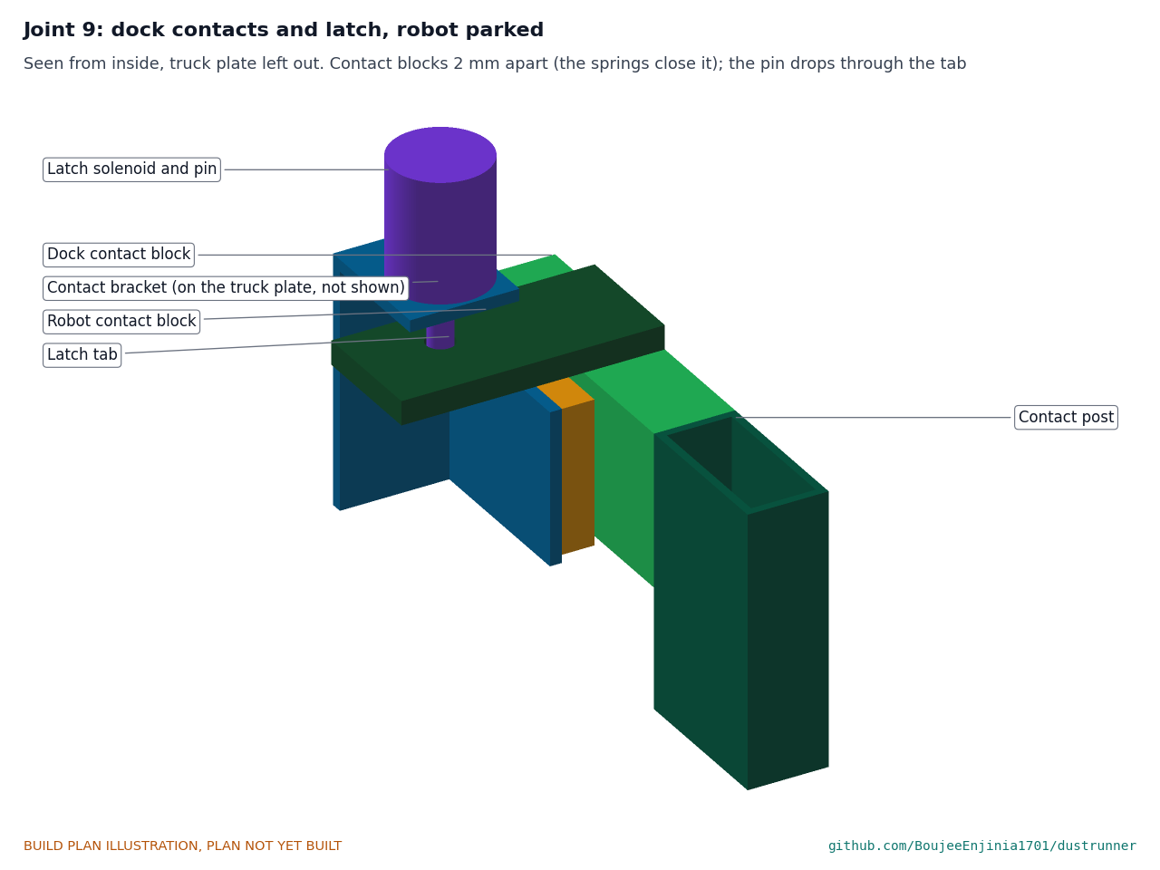
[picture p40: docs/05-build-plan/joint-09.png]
Figure 30. Joint 9: dock contacts and latch, robot parked


*Figure 30. Seen from inside with the truck plate left out: the contact blocks 2 mm apart, closed by the spring contacts; the pin through the tab.*

When the robot parks, its contact block stops 2 mm from the dock's block, which the spring contacts close; its pin rides up the chamfer and drops through the tab's hole. To leave, the robot lifts the pin for about a second.

**Check before moving on.** Each spring contact moves 3 mm freely; the tab hole lines up with the pin when the robot is pushed home by hand.

### 3.19 End stops (make 2)

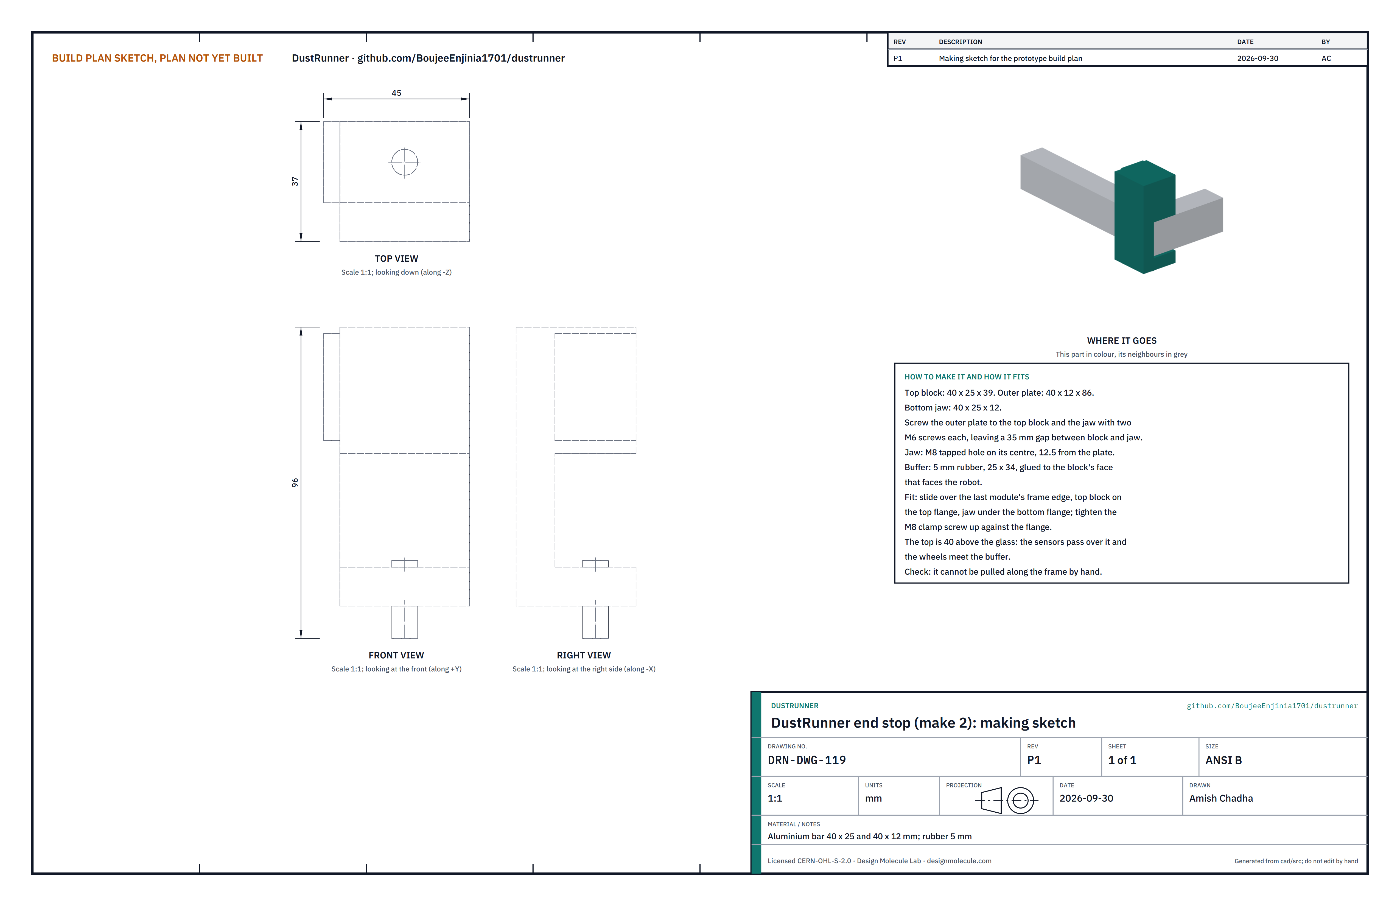
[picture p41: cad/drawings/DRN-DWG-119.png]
Figure 31. Making sketch of the end stop


*Figure 31. End stop making sketch (DRN-DWG-119).*

**What it is and what it is made from.** A clamp-on stop at the far end of the row on the lower and upper frame edges, the mechanical backstop to the IR sensors. Aluminium bar 40 x 25 and 40 x 12 mm; rubber 5 mm.

**How to make it.**

1. Cut a top block 40 x 25 x 39, an outer plate 40 x 12 x 86 and a bottom jaw 40 x 25 x 12.
2. Screw the outer plate to the top block and to the jaw with two M6 screws each, leaving a 35 mm gap between block and jaw.
3. Tap an M8 hole through the jaw on its centre, 12.5 from the plate.
4. Glue a 5 mm rubber buffer, 25 x 34, to the face of the top block that faces the robot.

**How it fits the parts next to it.**

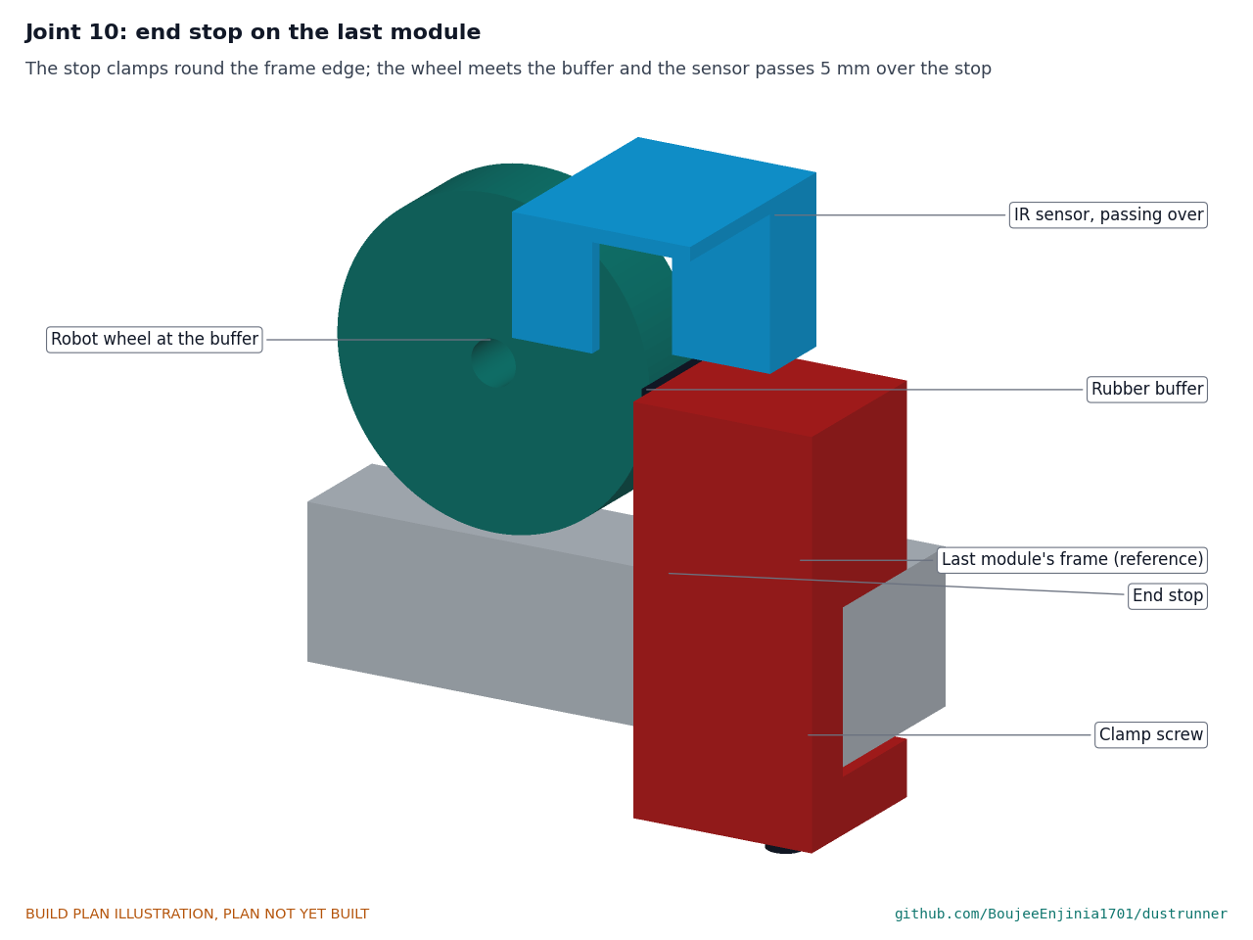
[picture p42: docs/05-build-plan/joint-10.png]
Figure 32. Joint 10: end stop on the last module


*Figure 32. The stop clamps round the frame edge; the wheel meets the buffer and the sensor passes 5 mm over the stop.*

Slide the stop over the last module's frame edge at the row end: top block on the top flange, outer plate down the frame's outer face, jaw under the bottom flange. Tighten the M8 clamp screw up against the flange. Its top is 40 above the glass, so the sensors pass over it and the wheels meet the buffer.

**Check before moving on.** The stop cannot be pulled along the frame by hand.

### 3.20 Bought components

Buy to specification, not brand. Line numbers are those of the bill of materials.

- **Microfiber sleeve and brush bearings (line 2).** Helical microfiber sleeve 120 mm outside for a 50 mm core, 2,198 long; two 20 mm bore 2-bolt flange bearing units with locking collars.
- **Brush gearmotor and drive (line 4).** 12 V DC gearmotor about 60 W, about 150 rpm out, face mounting; two HTD 3M pulleys and a belt for a 1:1 drive about 62 mm between centres.
- **Wheels and drive (line 5).** Four 70 x 18 mm polyurethane wheels with a 10 mm bore and a set screw or key; eight 10 mm bore 2-bolt pressed-steel flange bearings; four 10 mm steel axles; HTD 3M pulleys and a belt for 180 mm between centres per truck; two 6 to 10 mm shaft couplings.
- **Drive gearmotors (line 6).** Two 12 V 37 mm gearmotors with Hall encoders, about 10 W, face mounting.
- **Rollers and springs (line 7).** Four 22 mm guide rollers about 23 long with sealed bearings for an M8 bolt; two 16 mm hook rollers about 18 long for an 8 mm axle; two compression springs about 9 mm across giving 60 N at 20 mm; four M6 shoulder bolts.
- **Pack (line 8).** 12.8 V 10 Ah LiFePO4 pack with a BMS that cuts charging below 0 °C and above 45 °C, about 151 x 65 x 94 mm.
- **Controller (line 9).** ESP32-class board, a dual motor driver and a brush motor driver, current sensing, a humidity and temperature sensor and a driver for the latch solenoid, in an IP65 box about 140 x 80 x 55 mm with cable glands.
- **IR sensors (line 10).** Four sealed downward-looking reflective IR sensors.
- **Dock panel (line 12).** 20 W monocrystalline, about 530 x 350 mm, with mounting holes in its frame.
- **Charger, contacts and latch (line 13).** LiFePO4 solar charge controller about 5 A with a 14.4 V charge limit; three spring contacts with 3 mm travel; three copper contact strips; a 12 V spring-return pull solenoid with a 6 mm steel plunger and about 10 mm stroke.
- **Wiring and hardware (line 15).** Silicone wire, a 15 A fuse, a main switch, two latching emergency stop buttons for a 22 mm hole, M5 rivet nuts, stainless fasteners, cable ties, two pack straps.
- **Anemometer (line 16).** Cup anemometer with a pulse output, 0 to 30 m/s, on a 24 mm mast, and two U-bolt clamps.

#### 3.20.1 Wiring

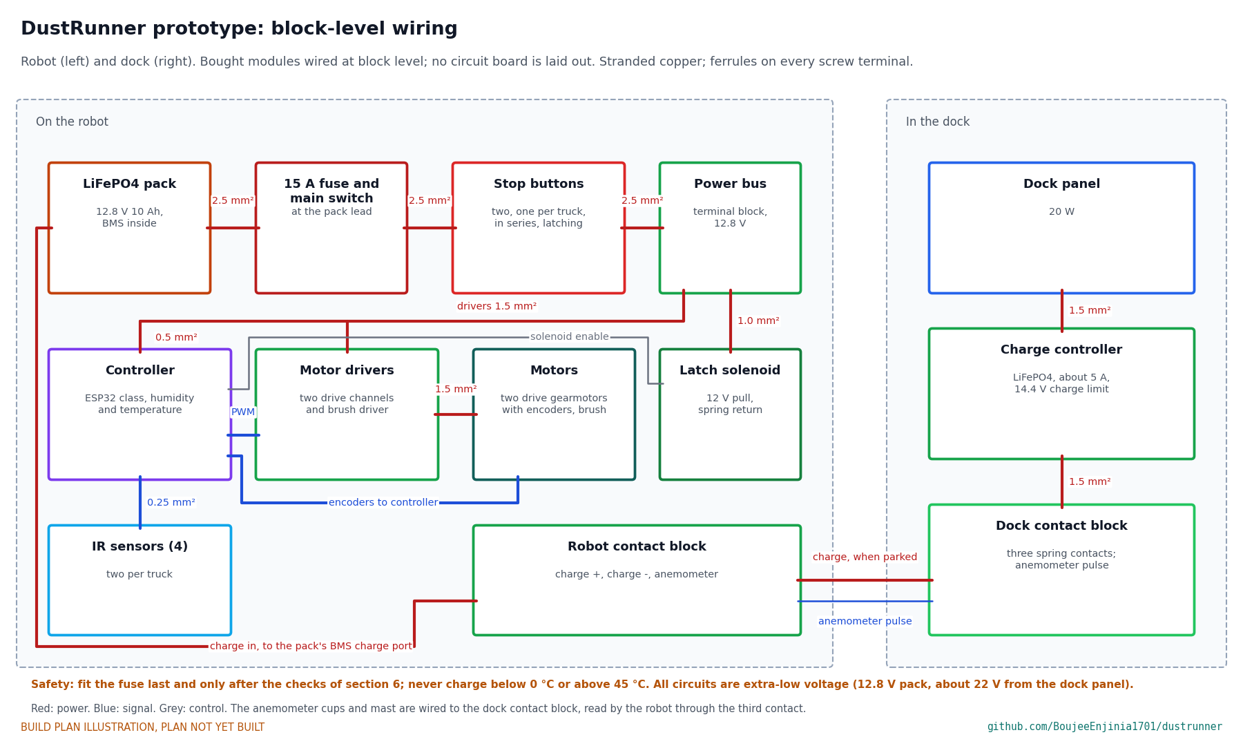
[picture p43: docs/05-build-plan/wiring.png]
Figure 33. Block-level wiring


*Figure 33. Block-level wiring with wire sizes. No circuit board is laid out; bought modules are wired together.*

Wire it like this, with stranded copper and a ferrule on every screw terminal:

1. Pack to the 15 A fuse and main switch, then through the two stop buttons in series to the power bus (a small terminal block): 2.5 mm². A stop button cuts all motor power.
2. Power bus to the motor drivers: 1.5 mm²; drivers to the three gearmotors: 1.5 mm².
3. Power bus to the controller: 0.5 mm²; power bus to the latch solenoid through its driver: 1.0 mm².
4. Controller to the drivers (speed signals), to the encoders, to the four IR sensors and to the solenoid driver: 0.25 mm².
5. Robot contact block to the pack's BMS charge port (charge positive and negative) and to the controller (anemometer signal).
6. In the dock: panel to the charge controller, charge controller to the dock contact block, and the anemometer's pulse lead to the third contact: 1.5 mm² for power.

**Check before moving on.** With the fuse out, every power wire reads open to the pack terminals; each stop button opens the motor feed; every wire is labelled.

## 4. Putting it together

In each picture the parts already fitted are grey and the part being fitted is in colour, with an arrow showing the way it goes in. Steps 1 to 3 are done on both trucks; the pictures show the lower one.

### Step 1: axles and wheels onto each truck plate

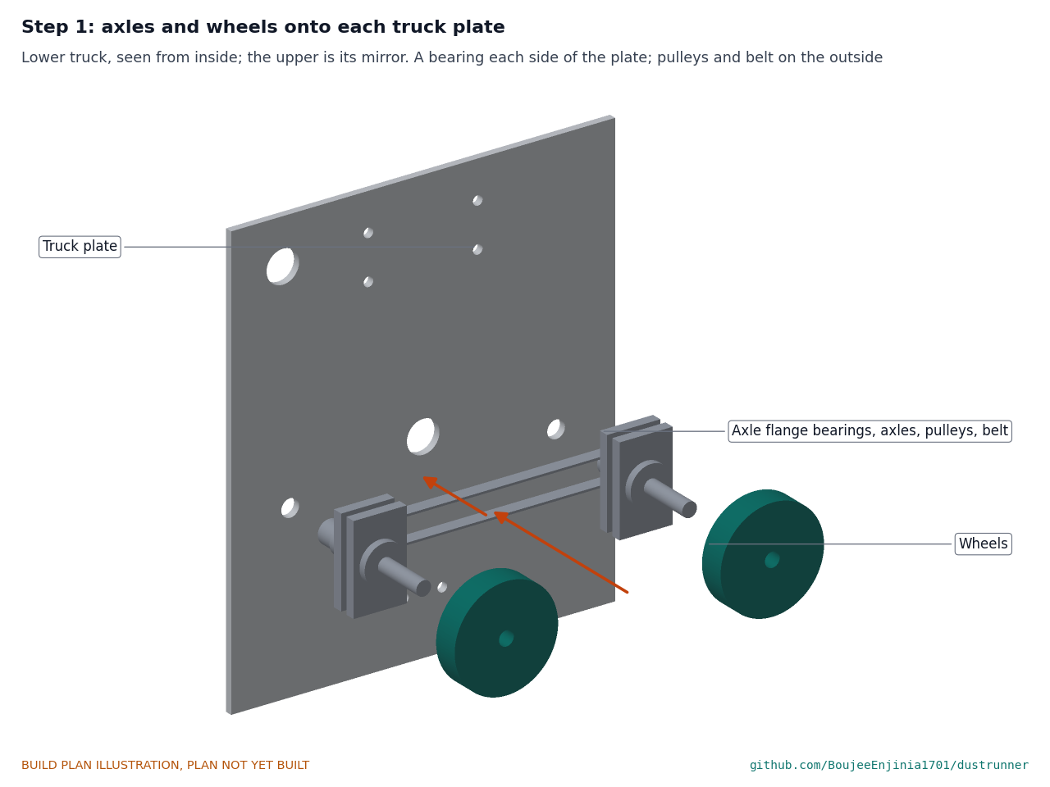
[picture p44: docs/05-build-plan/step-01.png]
Step 1


Bolt a flange bearing to each face of the plate at each axle hole. Slide the axle through, fit the wheel on the inside and the pulley on the outside, and fit the belt. Lock the bearing collars and the wheel set screws.

### Step 2: guide and hook rollers onto each plate

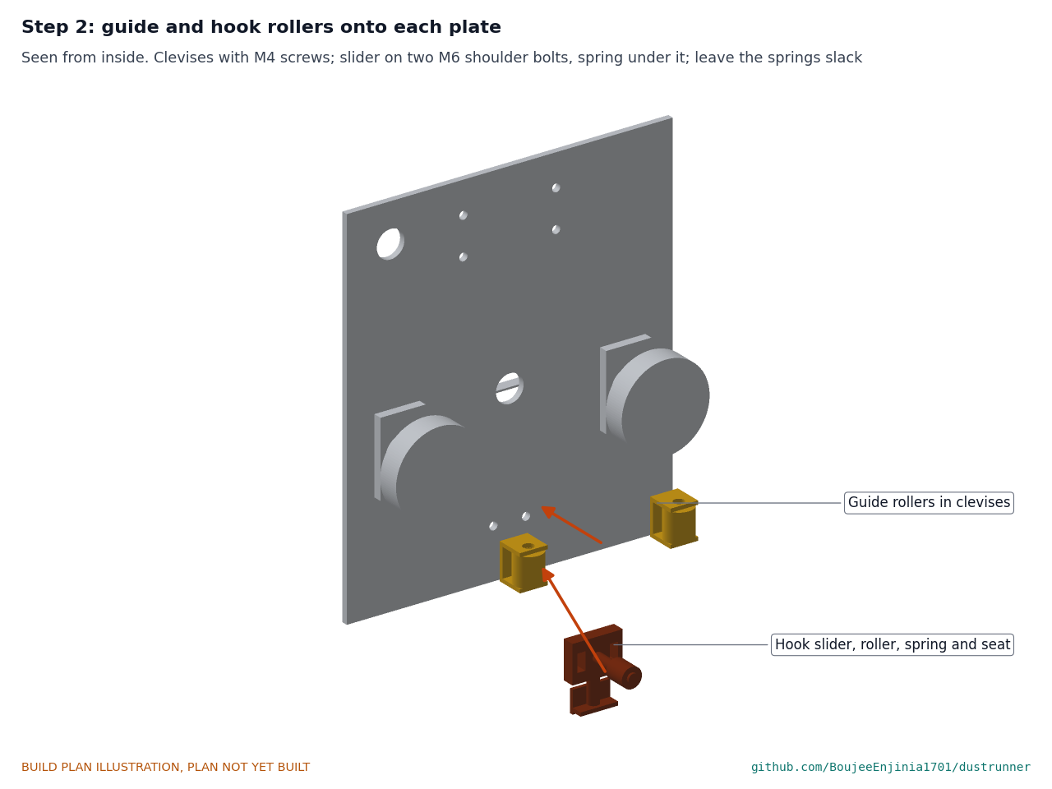
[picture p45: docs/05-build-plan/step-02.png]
Step 2


Screw the two clevises to the inner face with their rollers on M8 bolts. Fit the hook slider on its two shoulder bolts, the spring seat below it and the spring between them. The springs set the hook preload; it is checked in step 13.

### Step 3: brush bearing, sensors, stop button and contact bracket

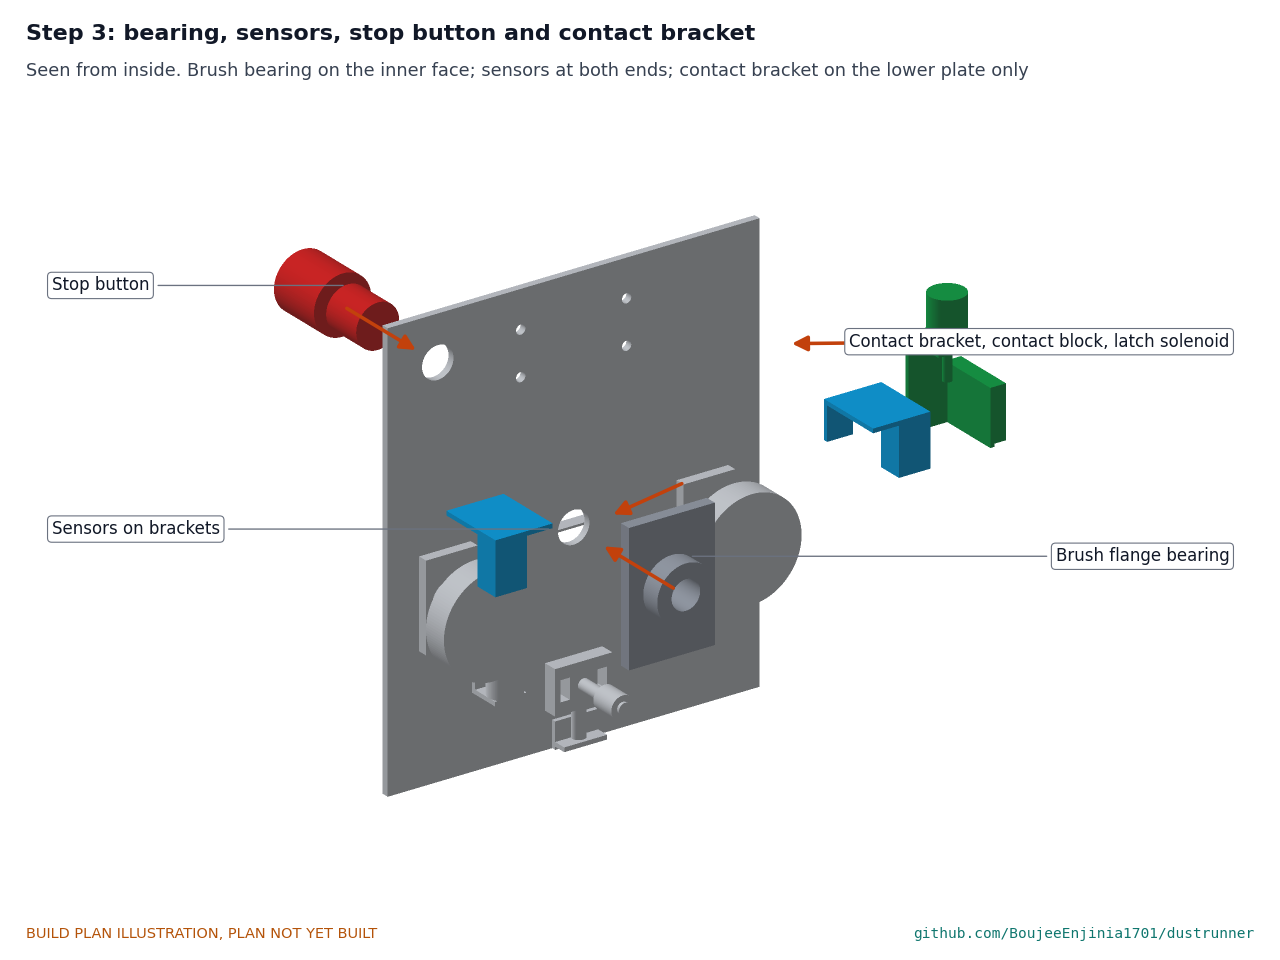
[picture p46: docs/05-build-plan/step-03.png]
Step 3


Bolt the brush flange bearing to the inner face, centred on the brush hole. Screw on the sensor brackets with their sensors. Fit the stop button through its hole from outside. On the lower plate only, screw on the contact bracket with the contact block and the latch solenoid.

### Step 4: beam onto the lower truck

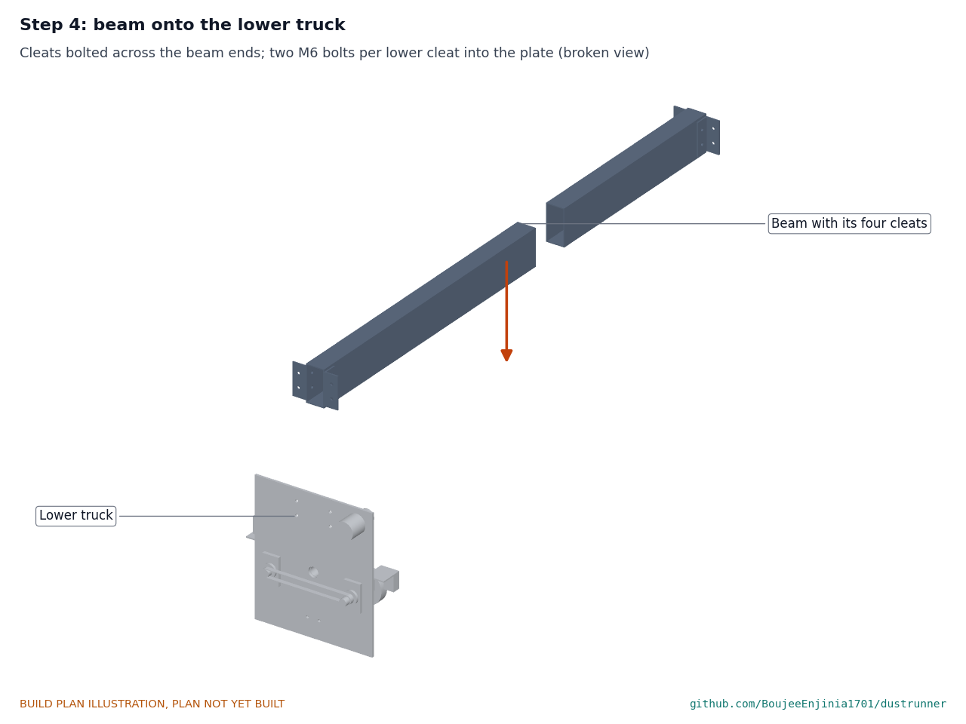
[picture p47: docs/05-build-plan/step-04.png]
Step 4


Bolt the four cleats across the beam ends with M6 bolts. Set the beam on the lower plate's inner face and fit two M6 bolts through each lower cleat into the plate, snug.

### Step 5: brush, then the upper truck

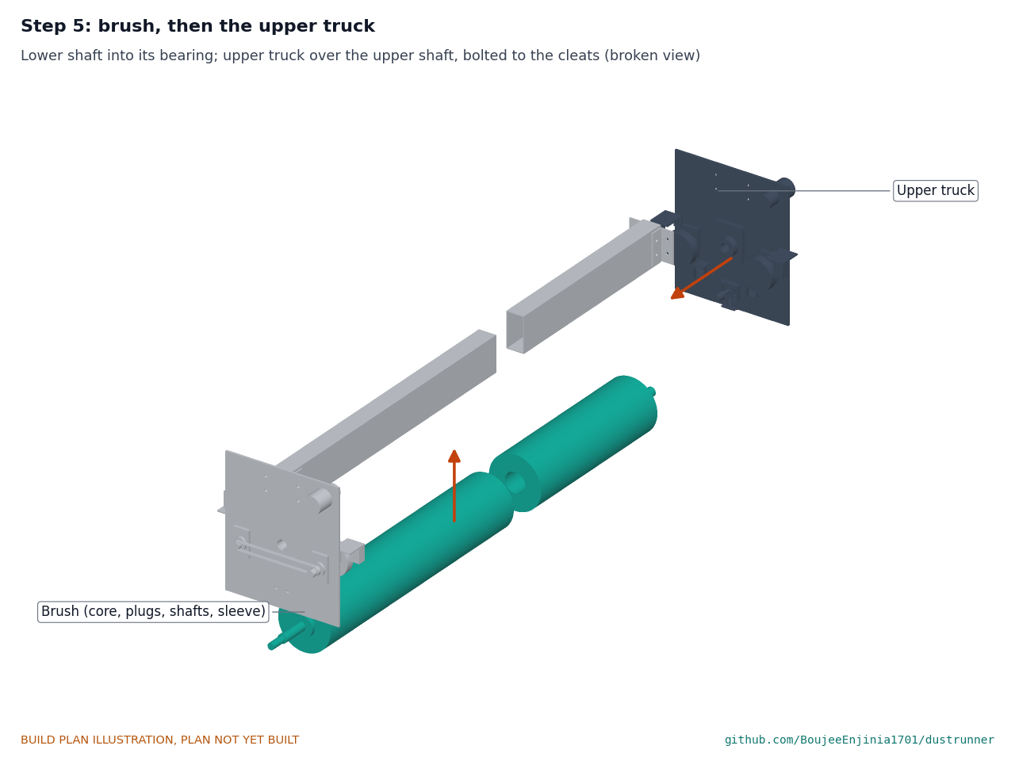
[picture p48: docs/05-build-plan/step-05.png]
Step 5


Slide the brush's lower shaft into the lower bearing. Slide the upper truck's bearing over the upper shaft, bring the plate against the upper cleats and bolt it. Square the trucks to the beam, tighten every cleat bolt and lock the brush bearing collars. **Hold point:** the brush turns freely by hand.

### Step 6: drive housings and motors

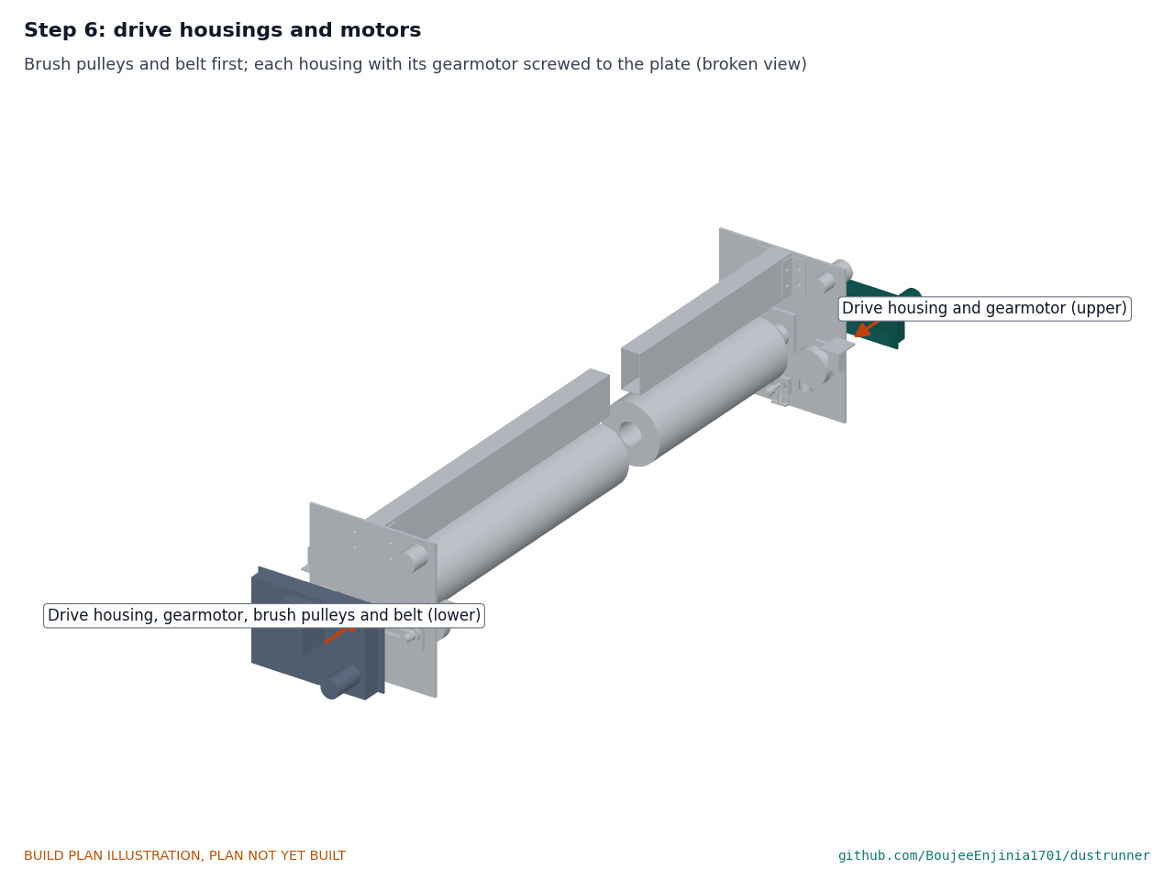
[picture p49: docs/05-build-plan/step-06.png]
Step 6


Fit the brush pulley on the lower shaft and the brush gearmotor's pulley and belt. Bolt each gearmotor to its housing's outer wall, join the drive motor's shaft to its axle with the coupling, and screw each housing to its plate by its flanges.

### Step 7: hood onto the beam

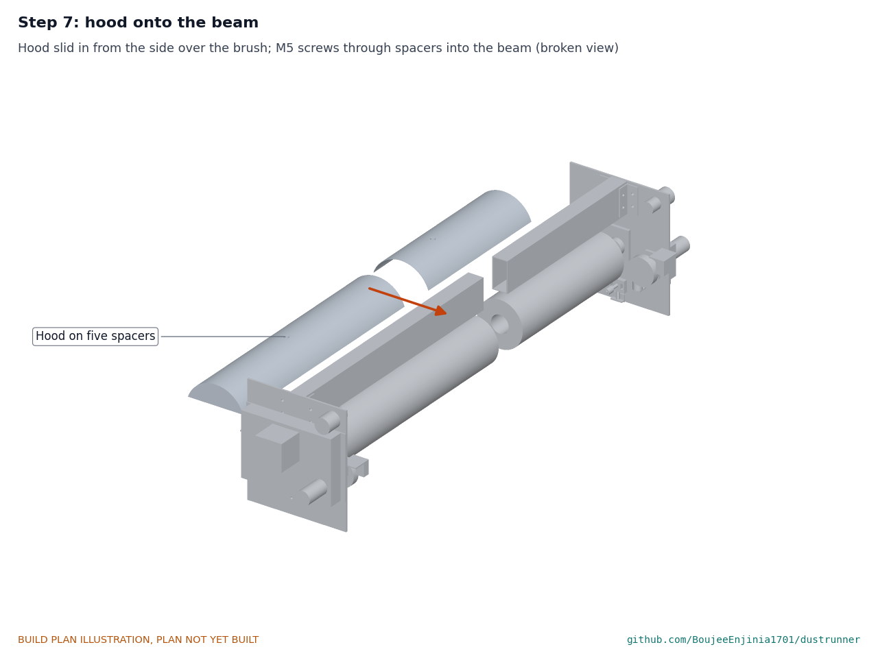
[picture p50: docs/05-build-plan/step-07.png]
Step 7


Slide the hood in from the side over the brush. Fit the five M5 screws up through the hood and the 3 mm spacers into the beam's rivet nuts.

### Step 8: pack, controller and sunshade

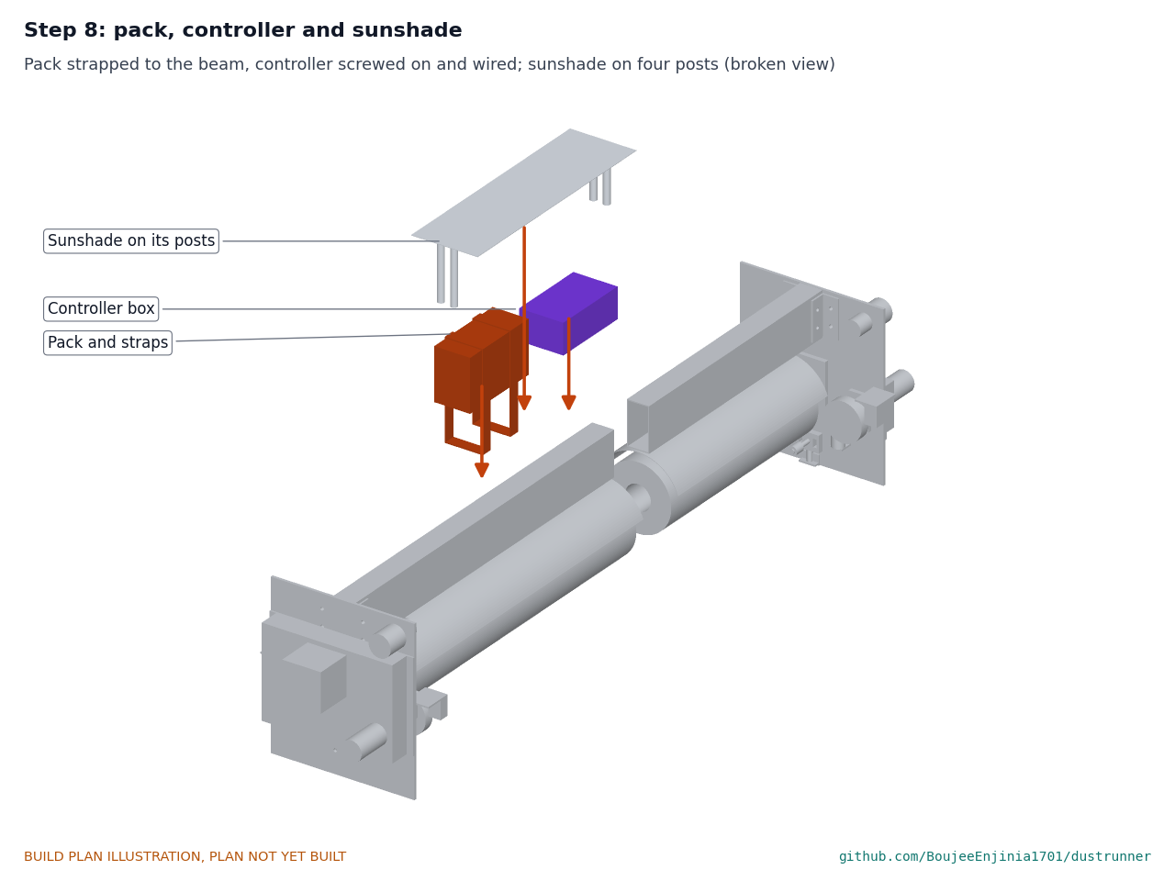
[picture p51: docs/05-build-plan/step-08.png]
Step 8


Strap the pack to the beam's top, screw on the controller box and wire them as Figure 33, with the fuse out. Fit the four posts and the sunshade. **Hold point:** the wiring checks of Section 3.20.1 pass.

### Step 9: dock frame on the ground

Step 9

Bolt two legs beside each of the far and rail-start cross members, and the three ties on top. Stand the frame at the start of the row, legs plumb.

### Step 10: near cross member and frame clamps

Step 10

Lay the clamp bars across the top of the near cross member and slide their module ends under the first module's long-side frame flange, jaws on top of the flange inside the frame. Tighten the M8 bolt at each jaw.

### Step 11: dock rails onto the cross members

Step 11

Screw the brackets inside the rails. Set each rail on its spacer (rail-start member) and its shim on the clamp bar (near member) and bolt through with M8 bolts. Add shims until each rail's top and outer face line up with the module frame with a 20 mm gap.

### Step 12: panel and charger

Step 12

Bolt the panel to the two panel ties through its frame holes, and screw the charger box to the far cross member's row side.

### Step 13: robot onto the dock rails

Step 13

Two people. Push the hook sliders down, slide the robot onto the rails from the dock's outer end with the wheels on the rail tops, the hook rollers under the bottom flanges and the guide rollers against the webs, then let the sliders up. Check each hook preload is 60 N (Section 5). **Hold point:** safety stop S5.

### Step 14: contacts, latch tab and anemometer

Step 14

Bolt the contact post to the rail-start cross member, then the contact block and latch tab on it, lined up with the parked robot. Clamp the anemometer mast vertical to the far cross member and run its lead to the dock contact block.

### Step 15: end stops onto the last module

Step 15

At the far end of the row, slide a stop over the lower and the upper frame edge of the last module and tighten each M8 clamp screw against the bottom flange. **Hold point:** safety stop S7.

## 5. First checks

These are the checks a TRL 4 test report would record; this plan only lists them. Requirement numbers are those of DRN-REQ-001.

*Table 2. First checks.*

| Check | Requirement | How | Pass when |
| --- | --- | --- | --- |
| Robot mass | R10 | Weigh the robot before step 13 | Mass recorded, within 0.5 kg of the 15.9 kg estimate |
| Hook preload | R9, R10 | Spring scale under each hook slider | 60 N per truck, give or take 5 N |
| Brush interference | R3 | Robot on the first module, brush still; measure the core's height above the glass at both ends and mid-span | Core 30 to 32 mm above the glass (sleeve pressed 3 to 5 mm into the glass plane); nothing but the sleeve within 10 mm of the glass |
| Frame fit | R4 | Push the robot by hand over the first module joint and along one module | Wheels stay on the flange; guide rollers stay on the web; no step stops it |
| Drives and stop buttons | R12 | Bench supply at 12.8 V in place of the pack, 5 A limit; run the brush and drives; press each stop button | Everything stops within 2 s; the brush ends are guarded |
| End stop | R9 | Drive slowly into the end stop with the IR sensors covered | The wheels meet the buffers; nothing else touches the stop |
| Latch | R9 | Drive into the dock; pull the robot toward the row by hand | The pin drops through the tab and holds; the solenoid lifts it |
| Dock charge | R8 | Panel in sun or a bench supply in its place; measure at the robot's contacts | Charge current flows only when parked; charge stops at 14.4 V |
| Anemometer | R9 | Spin the cups by hand; read the signal at the robot | The controller reads the pulses through the third contact |
| Coverage | R5 | Run once over a module dusted with flour | 98 % or more of the glass brushed |

## 6. Safety stops

Stop at each point. Carry on only when everything listed is true.

- **S1. Before the pack comes into the workshop.** Pack voltage about 12.8 to 13.4 V; no swelling, dents or damage; a datasheet from its maker showing the BMS and its 0 °C and 45 °C charge cut-offs. Fuse out. A charging spot ready on a non-combustible surface with a fire extinguisher for electrical fires within reach.
- **S2. Before the fuse goes in.** All wiring checks of Section 3.20.1 pass. Polarity at the pack and the drivers checked with a meter, not by wire colour.
- **S3. Before the motors first run.** Robot on stands with the wheels off the ground; drive housings fitted over the belts; hood fitted; hair tied back, no loose clothing; both stop buttons tested on a bench supply with a 5 A limit.
- **S4. Before the dock charges the pack.** The charge controller is set to the LiFePO4 profile (14.4 V) and measured at the contacts with the pack out; the pack's charge cut-offs are confirmed.
- **S5. Before the robot goes on the dock rails.** The dock is clamped to the first module and its legs are on firm ground; the array owner has agreed to the work and their electrical safety rules are followed; nothing on the robot or dock can reach array cables, connectors or junction boxes; gloves on (glass and frames can reach about 75 °C).
- **S6. Before the robot first leaves the dock under power.** The pack fuse is in; the IR sensors stop the drives when covered; the latch lifts and drops; the wind at the anemometer is below 6 m/s.
- **S7. Before the first run along the row.** Both end stops fitted and tight; nobody below or beside the row; one person at the dock lockout and one at the far end, each able to reach a stop button; the first runs are watched end to end.
- **S8. Before any unattended run (outside this plan).** A warning label on the robot, an audible start warning and a lockout switch at the dock are fitted, and the module maker's cleaning and frame-load guidance has been checked.

## 7. Tools, skills and workspace

**Tools.** Hacksaw with a 24 teeth per inch blade, or a bandsaw; bench vice with soft jaws; bench drill or a drill in a stand; drills 3 to 22 mm and a step drill; countersink; M4, M5, M6 and M8 taps; rivet-nut tool; files and a deburring tool; scriber, engineer's square, protractor, steel rule and calipers; feeler gauges; sheet-metal brake for 2 and 3 mm aluminium up to 240 mm long (or a sheet-metal shop); access to a lathe for the core plugs and lower shaft (or a turning shop); slip roll for the hood (or a shop); hand rivet tool; torque wrench; spring scale to 10 kg; digital angle finder and spirit level; ferrule crimper and wire strippers; multimeter; bench power supply 0 to 15 V, 0 to 5 A with a current limit; two stands to hold the robot off the ground.

**Skills.** No certified trade is needed. Basic metalwork (marking out, sawing, drilling, tapping, folding sheet), screw-terminal wiring and crimping, safe use of a bench power supply and care with lithium packs. All robot circuits are extra-low voltage (12.8 V pack, about 22 V from the dock panel); no mains wiring is part of this build. Work near the array follows the array owner's electrical safety rules.

**Workspace.** A bench about 2.5 m long, or two trestles, for the robot; a metalwork corner kept apart from the electronics; the charging spot of S1. For steps 9 to 15, a PV table with clear short edges, with the owner's agreement.

**Personal protective equipment.** Safety glasses for cutting, drilling and folding; cut-resistant gloves for plate and sheet; heat-resistant gloves at the array in daylight; hearing protection when sawing; no gloves near a turning drill or lathe.

## 8. Where the numbers come from

- Model and constructability checks: `cad/src/model.py` (`python cad/src/model.py --check`, 123 checks); STEP and STL exports in `cad/step/` and `cad/stl/`.
- Pictures: `cad/src/build_plan_media.py`, using `.kit/build_views.py`; written to `docs/05-build-plan/` and `cad/drawings/DRN-DWG-101` to `DRN-DWG-119`.
- General arrangement: `cad/drawings/DRN-DWG-001.pdf`, Rev P4.
- Calculations: `docs/04-calcs/01-sizing.md` (DRN-CAL-001 v0.3) and `docs/04-calcs/sizing.py`; mass [A3], [A4], hook preload [C0], wheel loads [C1], [C2], wind and latch [D1], [D2], end stop [D4], energy [F1] to [F7], cost [I1].
- Bill of materials: `bom/bom.csv`.
- Decisions: `docs/decisions/0003-design-for-construction.md` (DRN-DDR-003), with DRN-DDR-001 and DRN-DDR-002; open decisions in `docs/06-design-decisions.md` (DRN-DEC-001).
- Requirements: `docs/03-requirements.md` (DRN-REQ-001 v0.5).

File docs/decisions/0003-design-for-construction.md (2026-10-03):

---
doc_id: DRN-DDR-003
title: DustRunner design for construction
project: DustRunner
doc_type: Design decision record
version: "0.4"
status: Draft
date: '2026-10-02'
author: Amish Chadha
license: CERN-OHL-S-2.0
revisions:
- version: "0.1"
  date: '2026-09-30'
  author: Amish Chadha
  change: Changes that make the concept physically buildable, with the reason for each; made under Amish's 2026-09-30 instruction to make the design physically buildable; open for his review
- version: "0.2"
  date: '2026-10-01'
  author: Amish Chadha
  change: Budget treated as a value-engineering target
- version: "0.3"
  date: '2026-10-02'
  author: Amish Chadha
  change: Accepted by Amish on 2026-10-02, including the recommendations for A2 to A4
- version: "0.4"
  date: '2026-10-02'
  author: Amish Chadha
  change: 'Consequences updated: appearance model brought into line with the constructable design'
---

# 0003: Design for construction

- **Date:** 2026-09-30
- **Status:** accepted. Amish, 2026-10-02: "i approve your recommendations for all 555 open decisions." This covers every change in Tables 1 and 2 and the recommendations in Table 3 (A2 to A4), which are now decided as recommended and recorded in the design decisions register (DRN-DEC-001).

## Context

On 2026-09-30 Amish asked for the build plan to show how each component is made and how it fits the next, with pictures, and wrote: "If you are realising that the design cannot be built as per concept - fix the design assumptions to match and be physically feasible as you draw the illustrations." The TRL 3 model of DRN-CAL-001 v0.2 showed what DustRunner does but was a massing model: checking it with build123d (overlap volumes and gaps between solids) found parts that floated, rubbed, blocked each other or had no fixing. Problems P1 to P16 below are the ones found.

The changes keep what DustRunner does: the same full-width brush and its interference, the same wheels on the frame top flange, guide rollers on the frame face and sprung hook rollers under the bottom flange, the same pack, controller, sensors, dock with panel, contacts, latch and anemometer, and the same clamp-on end stops. The pitch and the safety case are unchanged; every guard and stop of the concept is still there, and the belts are now fully enclosed. Every change is in `cad/src/model.py`, which now runs 123 constructability checks (`python cad/src/model.py --check`): parts that must touch do touch, and parts that must stay apart are apart by at least the stated clearance, including the robot parked in the dock, at the end stop and on the module. All 123 pass.

## Decision

*Table 1. Changes made to the model, the BOM and the calculations.*

| # | Problem in the concept | Change made | Why this way |
| --- | --- | --- | --- |
| P1 | The 22 mm guide rollers filled the 22 mm gap between the truck plate and the frame face: each roller rubbed the plate, and nothing held its axle. | Plate gap 28 mm (was 22). Each roller turns on an M8 bolt in a folded 3 mm aluminium clevis screwed to the plate's inner face; it bears on the frame and stands 6 mm off the plate. | A clevis is the simplest bracket that carries a roller on both sides of its axle. 6 mm more gap is the least that fits the clevis back and a clearance. |
| P2 | The hook roller floated 2 mm above a rigid hook arm that was part of the plate; it had no axle and no spring, so the 70 N preload had no mechanism. | A 10 mm aluminium slider runs up and down the plate's inner face on two M6 shoulder bolts; the roller turns on an 8 mm axle cantilevered from it under the frame; a compression spring on a seat bracket pushes the slider up. The plate is 24 mm taller (296 mm) to carry the seat. | A slider and spring give a set preload that follows small frame height changes and can be backed off to fit the robot. Cantilevering the axle keeps everything under the flange inside the frame's 3 to 21 mm band and clear of the dock. |
| P3 | The wheel axles were stubs on the plate's inner face, yet a belt on the outer face linked them; a driven axle cannot be carried by a 5 mm plate alone. | Each 10 mm axle turns in two 2-bolt flange bearings, one each side of the plate; the pulley sits outboard. | Two bearings a plate's width apart carry the overhung wheel and the belt pull. |
| P4 | Both gearmotors and the brush motor floated outboard of the trucks with no fixing; the wheel belt passed through the brush shaft. | A folded aluminium drive housing on each truck (2 mm at the lower truck, 1.5 mm at the upper) covers the belts and carries the motors, face-mounted on its outer wall. The drive motor joins its axle through a shaft coupling. The wheel and brush belts run in separate layers; the brush stub shaft steps from 20 to 15 mm outboard of the plate to clear the wheel belt by 2.5 mm. | One part guards the belts (pinch points, R12) and mounts the motors. |
| P5 | The brush shafts butted against the core ends and passed through the plates with no bearing. | Turned aluminium end plugs pressed into the core; stub shafts pressed into the plugs; one 20 mm bore 2-bolt flange bearing on each plate's inner face. | The two "sealed bearings" of BOM line 2, made into parts that can be bolted on. |
| P6 | The beam butted against both plates with no fixing. | Two 30 x 30 x 3 mm angle cleats at each beam end, through-bolted across the beam and bolted to the plate. | Bolted cleats can be undone to change the module length (cut a new beam). |
| P7 | The hood floated 3 mm below the beam; the sunshade floated 6 mm above the pack. | Five 3 mm nylon spacers and M5 screws into rivet nuts in the beam's bottom wall hang the hood; four 12 mm tube posts on M5 screws carry the sunshade 6 mm above the pack. Two straps hold the pack to the beam. | Keeps the gaps the concept intended (hood clearance, air under the shade) with plain fixings. |
| P8 | The IR sensors and the robot's contact pad were butted against the plate's end edge. | Folded 3 mm brackets screwed to the plate's inner face carry the sensors 44 mm above the frame, and a folded bracket carries the robot contact block. | Brackets on the face, not the edge. |
| P9 | The dock latch had no parts: the dock's "latch with a 6 mm pin" had nothing to engage on the robot, and no way to release. | A 12 V spring-return pull solenoid on the robot's contact bracket: its 6 mm pin drops through a hole in a 6 mm latch tab on the dock contact block when the robot parks, and the robot lifts it for about a second to leave. The tab's free end is chamfered so the pin rides up onto it. | Keeps the 6 mm pin in shear that DRN-CAL-001 [D2] checks. A sprung pin that drops in by itself fails safe (latched); the robot already has power and a controller to lift it, so the dock needs no new electronics. |
| P10 | The dock contact block floated 89 mm above the dock frame. | A 40 x 20 mm tube contact post bolted to the rail-start cross member carries the dock contact block, with the latch tab on top. | Places the contacts where the robot's block arrives, 2 mm apart when parked. |
| P11 | Two dock posts sat under the rails in the hook roller's path, so the robot could not leave the dock; the cross members did not reach the rails; the clamps were connected to nothing. | Cross members are 40 x 40 x 2 mm tube, 6 mm below the rail bottom and starting 30 mm inside the rail, clear of the hook roller path. Each rail is held by folded 4 mm L brackets inside the channel (screwed through the web with flush countersunk screws) and bolted down through a spacer (rail-start member) or a shim on a clamp bar (near member). | The robot's wheels, guide rollers and hook rollers wrap all three outside faces of the rail, so a rail can only be held from inside its channel. |
| P12 | The dock clamps did not grip the module frame. | Each frame clamp is a 40 x 6 mm bar under the first module's long-side bottom flange and a 6 mm jaw on top of the flange inside the frame, with a 2.5 mm spacer beside the flange edge and one M8 bolt. The bar's other end bolts to the near cross member. | Grips the frame's return flange without drilling (R6). |
| P13 | The dock legs met the tilted cross members at an angle with no fixing, and stood on nothing. | 40 x 40 x 2 mm square-tube legs stand vertical beside the far and rail-start cross members, bolted through both with two M8 bolts, on 100 x 100 x 6 mm foot plates. Three 40 x 20 mm ties on top join the far and rail-start members and carry the panel. | Side-by-side bolting works at any tilt; the ties make the dock one frame and give the panel its mounting. |
| P14 | The anemometer mast stood normal to the tilted table, 25° off vertical. | The mast is vertical, held by two U-bolt clamps on the far cross member. | Cup anemometers are made to read with a vertical axis. |
| P15 | The end stop was taller than the IR sensors' height, so a sensor housing hit it before anything else; it had no clamp screw. | End stop made of three screwed pieces (top block, outer plate, bottom jaw) with an M8 clamp screw up against the frame's bottom flange; its top is 40 mm above the glass, so the sensors pass 5 mm over it and the wheels meet the rubber buffer. | The wheel tyre and buffer take the impact [D4]; the sensors are not a structural stop. |
| P16 | The module's long-side frames were modelled solid, so the clamp had nothing to grip. | Reference module ends modelled as C sections like the edges (context only, not in the BOM). | Makes the frame clamp's fit checkable. |

*Table 2. Knock-on changes.*

| Item | Change | Reason |
| --- | --- | --- |
| Mass | 15.9 kg (was 13.8 kg): parts added for construction about 2.1 kg [A4]. | Bearings, housings, brackets, clamps and fittings that the massing model left out. |
| Hook preload | 60 N per truck (was 70 N), set by the same rule as before: the highest preload that keeps the steady brushing wheel load at 60 N or less at every tilt [C0]. Wheel loads 56 N brushing at 25°, 59 N worst tilt, 73 N at row entry; traction margin 1.30 at the 6 m/s start limit (was 1.33). | The heavier robot presses harder on the frames, so less spring is needed for the same wheel load. |
| Beam and span | Beam 2,334 mm (was 2,322); plates 28 mm outboard of the frame. Robot 2,556 mm across the slope with the motors (was 2,488). | Plate gap and drive housings. |
| Cost | BOM lines 2, 5, 7, 11, 13, 14, 15 and 16 repriced: $573.00 (was $500.00) [I1]. Payback on a 60 m row 3.2 years (was 2.8); 3 years from 63.5 m [I9]. | Parts added for construction. |
| Drawing | DRN-DWG-001 Rev P3; making sketches DRN-DWG-101 to 119 added. | Follows the model. |
| Documents | DRN-CAL-001 v0.3, DRN-REQ-001 v0.5, DRN-PRC-001 v0.5 updated. R10 (mass), R13 and R14 now not met; no target changed. | Follows the model. |
| Wind, stopping, energy | Parked and running wind checks still hold with factors over 4; brush and robot stop in 0.13 and 0.07 s; 68 W cleaning, 7.7 Wh per 40 m cycle. | Recalculated in DRN-CAL-001 v0.3. |

*Table 3. Items that change a requirement: proposed, then accepted by Amish as recommended on 2026-10-02 (A1 is a value-engineering note, not a decision).*

| # | Question | Options | Recommendation |
| --- | --- | --- | --- |
| A1 | Parts now cost $573 against the value-engineering target of $500 (`budget_usd`, a hypothetical control target), USD 73 over. | No decision needed. The target stays $500; savings worth trying at quotes are cheaper bearings and a lighter dock. | Carry in the value engineering section of DRN-DEC-001. |
| A2 | The robot weighs 15.9 kg against R10's 15 kg, though every wheel load meets R10. | (a) restate R10's mass limit as 16.5 kg, keeping the 60 N and 75 N wheel-load limits that protect the modules; (b) find about 1 kg (4 mm truck plates, pocketed plates, 1.5 mm lower housing); (c) both: restate now, weigh at TRL 4. | (c). Accepted 2026-10-02: R10's mass limit is 16.5 kg, wheel-load limits unchanged. |
| A3 | At $573 the payback on a 60 m row is 3.2 years (R14 not met); 3 years needs a row of about 64 m. | (a) restate R14 as "3 years or less on rows of 65 m or more"; (b) keep R14 and treat it as at risk until quotes; (c) relax it to 3.5 years on 60 m. | (b), revisited once quotes exist. Accepted 2026-10-02: R14 is kept and marked at risk. |
| A4 | Latch release: the robot lifts its own latch pin with a solenoid (P9). | (a) robot-side solenoid as modelled; (b) solenoid on the dock, switched through a fourth contact; (c) a passive latch the robot pulls out of with its drives (no pin in shear, so the parked wind case must be rechecked). | (a). Accepted 2026-10-02. |

## Consequences

- With A2 to A4 accepted (2026-10-02): R10's mass limit is restated as 16.5 kg (DRN-REQ-001), so the 15.9 kg robot meets it on paper and is weighed at TRL 4; R14 stays at 3 years on rows of 60 m or more and is at risk until quotes; the robot-side solenoid stays as drawn.

- `design_state: constructable` in `project.yaml`. The build plan DRN-BLD-001 shows every component and step in pictures generated from the model (`cad/src/build_plan_media.py`). Open decisions are in the design decisions register DRN-DEC-001.
- Requirement status (DRN-CAL-001 v0.3): 5 met, 3 at risk (R4, R9, R11), 3 not met (R10 on mass, R13, R14), 4 not verifiable at TRL 3. Before: 7 met, 4 at risk, none not met.
- The appearance model `cad/src/product_model.py` now takes the trucks, hook arms, dock, legs and mast from the constructable design in `cad/src/model.py`. The photoreal renders (`media/render-*.png`), `media/card.png` and `media/social-preview.png` are made from it on Amish's Mac, where Blender is.
- The module frame's bottom flange width and the room above it for the clamp jaw, and the parts' real masses, are checked when parts are bought (TRL 4).

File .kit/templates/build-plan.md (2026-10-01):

---
doc_id: PRJ-BLD-001
title: Project prototype build plan
project: Project name
doc_type: Build plan
version: "0.1"
status: Draft
date: YYYY-MM-DD
author: Amish Chadha
license: CERN-OHL-S-2.0
revisions:
  - version: "0.1"
    date: YYYY-MM-DD
    author: Amish Chadha
    change: First build plan; design made constructable
---

# Project prototype build plan

**Plan, not yet built.** How to build the first proof-of-concept prototype, component by component. Building and testing to it is TRL 4 work. Decisions still to be made are kept in the design decisions register (`docs/06-design-decisions.md`), not here.

## 1. What you are building

Every component, pulled apart and numbered in build order

One short paragraph: what the prototype is, how many components, which are made and which are bought, and the main ways they are made.

## 2. What changed to make it buildable

| Component | The concept had | The buildable design has | Why |
| --- | --- | --- | --- |

## 3. Making the components

### 3.1 Component name

Making sketch

**What it is and what it is made from.**

**How to make it.**

1. Mark out ...
2. Cut ...

**How it fits the parts next to it.**

Close-up of the joint

**Check before moving on.**

## 4. Putting it together

### Step 1: ...

Step 1

## 5. First checks

| Check | Requirement | How | Pass when |
| --- | --- | --- | --- |

## 6. Safety stops

## 7. Tools, skills and workspace

## 8. Where the numbers come from

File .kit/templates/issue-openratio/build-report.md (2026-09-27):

---
name: Build report
about: Tell us what happened when you built, printed or tested part of this design
title: "Build report: "
labels: build-report
---

This is a research and educational prototype, not a medical device. It is a TRL 3 concept and is not released for fabrication. If you build any part of it, you do so at your own risk. Reports help everyone.

**What you built** (part, sub-assembly or test)

**Materials, tools and settings**

**What worked**

**What did not work, with photos or measurements if you have them**

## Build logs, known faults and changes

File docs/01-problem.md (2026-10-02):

---
doc_id: DRN-PRB-001
title: DustRunner problem statement
project: DustRunner
doc_type: Problem statement
version: "0.5"
status: Draft
date: '2026-10-02'
author: Amish Chadha
license: CERN-OHL-S-2.0
revisions:
- version: "0.1"
  date: '2026-09-24'
  author: Amish Chadha
  change: Initial scaffold
- version: "0.2"
  date: '2026-09-25'
  author: Amish Chadha
  change: Populate to TRL 2 (problem, users, context, constraints, prior work)
- version: "0.3"
  date: '2026-09-25'
  author: Amish Chadha
  change: Apply DRN-DDR-001 (problem line reworded to a monthly loss in the dusty season; first table format decided; pilot partner still open)
- version: "0.4"
  date: '2026-09-26'
  author: Amish Chadha
  change: Stronger sources
- version: "0.5"
  date: '2026-10-02'
  author: Amish Chadha
  change: First candidate pilot site and co-design partner, as decided by Amish on 2026-10-02
---

# DustRunner problem statement

Soiling cuts output of PV arrays in dusty regions by up to 15 to 25% a month in the dusty season, and water for washing is scarce. Utility-scale plants solve this with water-free cleaning robots, but small and mid-size ground-mounted arrays of tens of kilowatts, which are common on farms, mini-grids and commercial sites in the same regions, are still washed by hand with water or left dirty.

## The problem

Dust settles on PV glass every day. In desert climates the loss grows quickly between cleanings. Qatar's QEERI test facility measured a soiling rate of about 0.49 % per day on fixed-tilt modules, about 13 % a month without rain or cleaning, and losses of up to 60 % over long uncleaned periods ([PV Tech, "Challenges of PV soiling in desert climates"](https://www.pv-tech.org/challenges-of-pv-soiling-in-desert-climates/)). A 2026 study for Arar, Saudi Arabia, assumed monthly losses of about 4 % in winter rising to 15 % in June and July ([Alharbi, Energies 19(18) 4373](https://www.mdpi.com/1996-1073/19/18/4373)). The "up to 15 to 25 % a month" in the summary above is therefore the loss of an array left uncleaned for a month or more in the dusty season, not a year-round average.

Worldwide, soiling cost at least 3 to 4 % of solar production in 2018, about 3 to 5 billion euros of revenue, with 4 to 7 % projected for 2023 ([Ilse et al., Joule 3, 2303 to 2321, 2019](https://www.cell.com/joule/fulltext/S2542-4351(19)30422-2); [open access PDF](https://elib.dlr.de/129424/1/Joule-ils.pdf)).

Washing with water works but uses water where it is scarcest. Field trials found about 3.5 L to more than 10 L of water used to clean and rinse a single module ([Polywater, "Water consumption in PV panel cleaning"](https://www.polywater.com/wp-content/uploads/2021/08/SPW-Intl-blog-Water-Use-IndiaCA.pdf)). Manual cleaning also needs labor, so small owners stretch the interval: the cost-optimal manual interval came out at about 60 days, and longer at low tariffs ([Alharbi, 2026](https://www.mdpi.com/1996-1073/19/18/4373)), and the array runs dirty for most of that time.

The underlying gap is that each manual cleaning is expensive, so it happens rarely. A small robot that cleans dry every day changes that trade-off, provided it is cheap enough for one row and does not damage the glass.

## Users and context

| User | Need | Context |
| --- | --- | --- |
| Owner of a small ground-mounted array | More energy from the same array without buying water or hiring cleaners | Farms (solar irrigation pumping), mini-grids, schools and clinics, small commercial sites; 10 to 200 kW |
| O&M technician or site caretaker | A machine that runs itself, is easy to install on an existing row and is repairable with local parts | Visits the site weekly or less |
| Mini-grid or community solar operator | Predictable yield and lower operating cost in the dry season | Arrays of several rows, remote sites |
| Open hardware community | A documented, buildable reference design to adapt to other module and table sizes | Makerspaces, university labs, technical colleges |

Operating context assumed for the concept:

- **Climate:** hot, dry and dusty (for example the Middle East and North Africa, the Sahel, northwest India and the US Southwest). Ambient 0 to 50 °C, glass up to about 75 °C, nightly dew possible in coastal and desert areas.
- **Arrays:** fixed-tilt ground-mounted tables, one module high in portrait (1P), tilt 10 to 35°, rows 20 to 100 m long. Modules of about 2,278 x 1,134 mm with 30 to 35 mm aluminum frames are now common ([DAS Solar 590 W example](https://www.solar-hub.co.uk/products/590w-das-solar-n-type-grey-frame-2278-x-1134)).
- **Dust:** mostly dry, loose mineral dust between rain events. Cemented dust after dew, bird droppings and lichen are outside what dry brushing can remove.

## Prior work

- **Ecoppia** (Israel, India, United States): water-free robots that use microfiber elements and airflow, charge from their own onboard solar module and clean utility-scale rows nightly and autonomously ([Ecoppia technology](https://www.ecoppia.com/technology/)). Sold to large plants as a service.
- **NOMADD** (Saudi Arabia): the "NO-water Mechanical Automated Dusting Device", designed to clean every panel as often as daily in desert plants, at about 10 US cents per watt of added cost ([RenewEconomy](https://reneweconomy.com.au/desert-solar-panel-cleaners-water-free-88183/)).
- **SolarCleano F1** (Luxembourg): an 82 kg operator-moved robot with 1.2 m helical brushes, dry or wet, up to 1,200 m²/h, able to cross gaps up to 70 cm ([SolarCleano](https://www.solarcleano.com/products/remote-solarcleano-f1)). Suited to contractors, not to a single small row.
- **Academic prototypes:** for example a tracked robot with two helical brushes and ultrasonic sensing for desert PV ([Antonelli et al., Mechatronics, 2020](https://www.sciencedirect.com/science/article/abs/pii/S0957415820300520)).
- **Robotic cleaning cost** on utility-scale plants is about 2.4 to 8.2 € per m² of module area ([Ilse et al., 2019](https://elib.dlr.de/129424/1/Joule-ils.pdf)).

The gap DustRunner targets is an open, garage-buildable robot for one small row that installs without rails and costs less than one or two years of the energy it recovers.

## Constraints

- Garage-buildable prototype, $500 USD (`budget_usd`) for one robot, its dock and its anemometer, using off-the-shelf motors, aluminum sections and hobby electronics.
- Must not void or endanger module warranties. Manufacturers forbid abrasive cleaning and some require prior approval of motorized cleaning tools; First Solar, for example, reviews automated tools and gives no warranty for modules damaged by cleaning ([First Solar module cleaning guidelines](https://www.firstsolar.com/-/media/First-Solar/Technical-Documents/Series-4-Application-Note/Module-Cleaning-Guidelines.ashx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)). Abrasion of anti-reflective coatings by robots is still being studied in the field ([PV Tech](https://www.pv-tech.org/challenges-of-pv-soiling-in-desert-climates/); [Ilse et al., 2019](https://elib.dlr.de/129424/1/Joule-ils.pdf)).
- No drilling of modules or of the mounting structure; only clamp-on parts.
- Works on an energized array. PV strings can carry DC voltages of several hundred volts, so the robot must never touch cables, connectors or junction boxes.
- No water and no consumables other than replaceable microfiber.

> **Safety:** DustRunner is unattended moving machinery with a lithium iron phosphate battery, working on an energized PV array on hot glass up to about 1.6 m above the ground. The hazards and the measures against them are in DRN-PRC-001, Safety.

## Out of scope

- Utility-scale plants, single-axis trackers and rooftop arrays.
- Automatic transfer from row to row (one robot per row, or carried by hand).
- Wet cleaning, bird droppings and cemented soiling.
- A commercial cleaning service or fleet software.

## Open questions

- Which pilot site and co-design partner to work with first (a solar pumping farm, a mini-grid operator or a university test array)? Decided by Amish on 2026-10-02: a university or national lab outdoor PV test site in a dusty climate, with Arizona State University's Photovoltaic Reliability Laboratory in Mesa as the first candidate to approach (DRN-DEC-001).
- First module and table format: decided by Amish on 2026-09-25 as 1P portrait tables of 2,278 mm modules (DRN-DDR-001, D10). The visible frame flange width of target modules still needs a survey (DRN-CAL-001, C12).
- Is daily dry cleaning effective on the local dust, or does dew cementation limit it? This needs site dust data and later testing.

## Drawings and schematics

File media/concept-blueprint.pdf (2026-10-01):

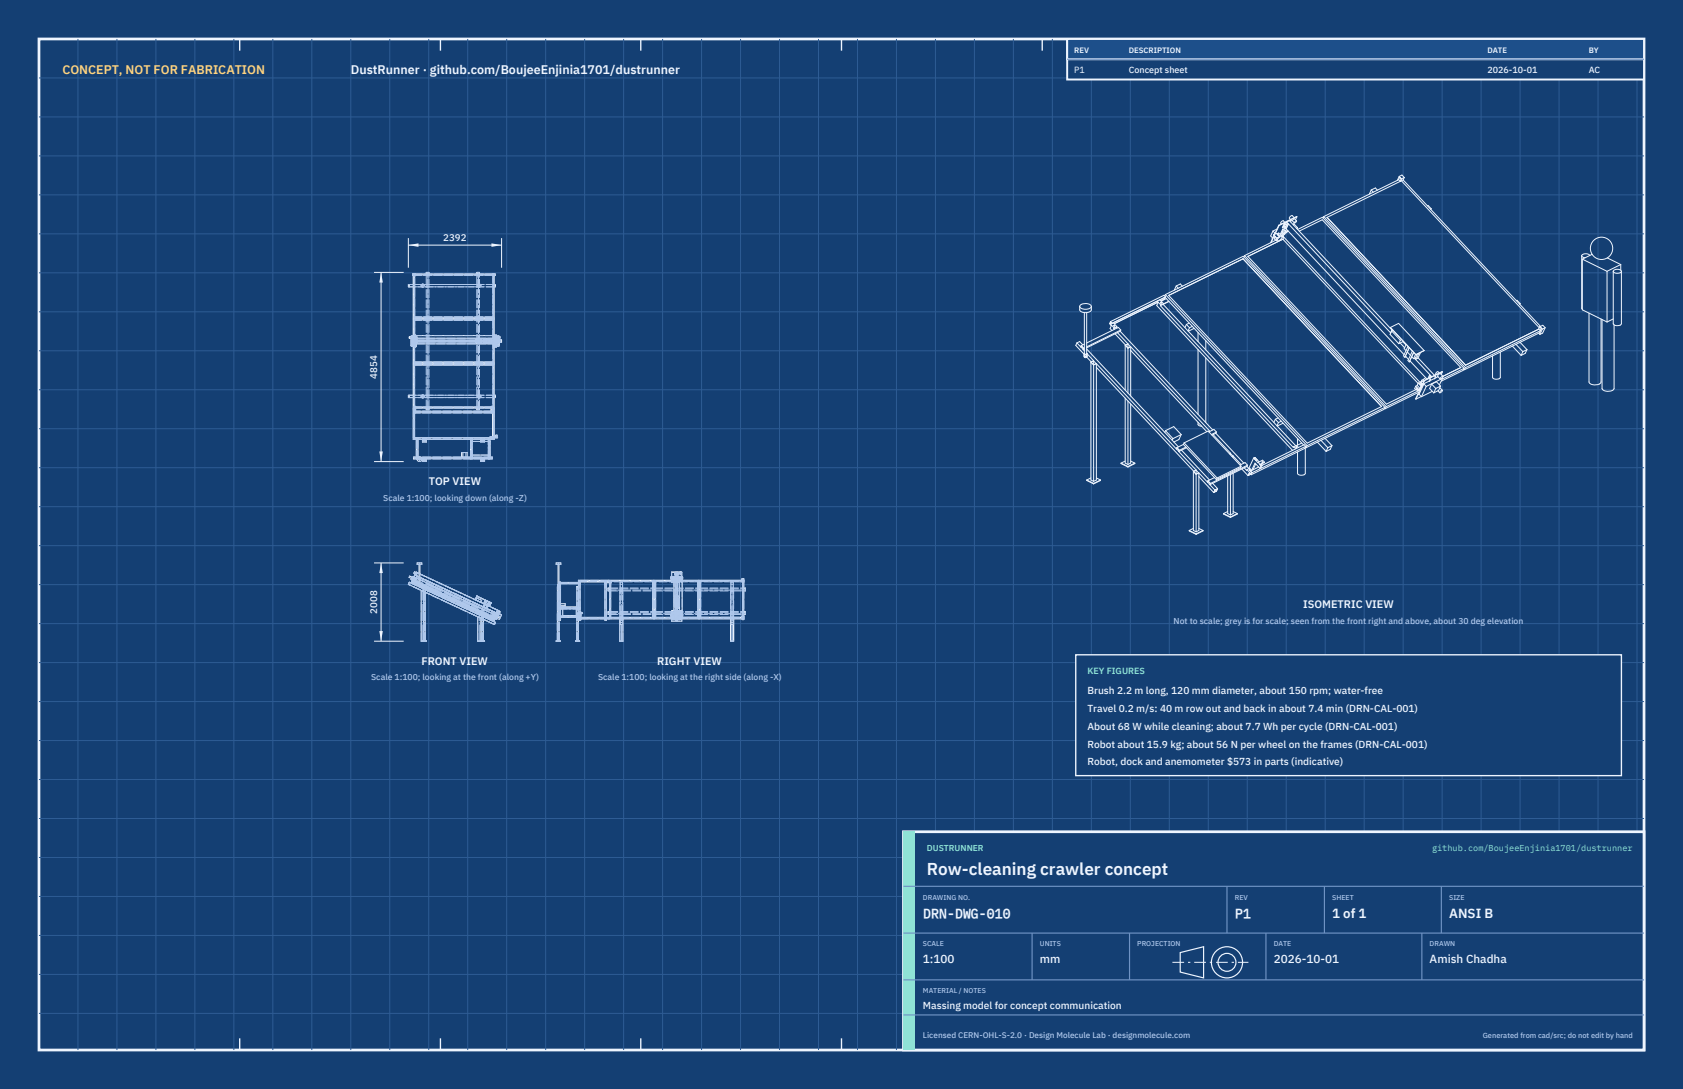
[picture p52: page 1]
CONCEPT, NOT FOR FABRICATION; DustRunner · github.com/BoujeeEnjinia1701/dustrunner; FRONT VIEW; TOP VIEW; RIGHT VIEW; ISOMETRIC VIEW; REV; DESCRIPTION; DATE; Concept sheet; DUSTRUNNER; github.com/BoujeeEnjinia1701/dustrunner; DRAWING NO. DRN-DWG-010; REV P1; SHEET 1 of 1; SIZE ANSI B; SCALE 1:100; UNITS mm; PROJECTION; DRAWN Amish Chadha; Licensed CERN-OHL-S-2.0 · Design Molecule Lab · designmolecule.com; Generated from cad/src; do not edit by hand

Scale 1:100; looking down (along -Z)

Not to scale; grey is for scale; seen from the front right and above, about 30 deg elevation

KEY FIGURES
Brush 2.2 m long, 120 mm diameter, about 150 rpm; water-free
Travel 0.2 m/s: 40 m row out and back in about 7.4 min (DRN-CAL-001)
About 68 W while cleaning; about 7.7 Wh per cycle (DRN-CAL-001)
Robot about 15.9 kg; about 56 N per wheel on the frames (DRN-CAL-001)
Robot, dock and anemometer $573 in parts (indicative)

Scale 1:100; looking at the front (along +Y)

Scale 1:100; looking at the right side (along -X)

Row-cleaning crawler concept

MATERIAL / NOTES
Massing model for concept communication

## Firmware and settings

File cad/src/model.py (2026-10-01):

"""DustRunner parametric model (build123d), TRL 3, constructable level of detail (DRN-DDR-003).

Run from the repo root:
    python cad/src/model.py            exports STEP and STL and prints the constructability checks
    python cad/src/model.py --check    prints the constructability checks only
Exports into cad/step and cad/stl:
    dustrunner-robot.step / .stl       the robot (items 1 to 10 of bom/bom.csv, with its fittings)
    dustrunner-dock.step / .stl        clamp-on dock with panel, charger, contacts, latch tab and anemometer (11 to 13, 16)
    dustrunner-end-stop.step / .stl    pair of clamp-on end stops (14)
    dustrunner-assembly.step           robot parked in the dock at the start of the row, with one
                                       reference module and an end stop pair (reference module not in the BOM)

Local table coordinates (mm), used for every part:
    X = u  along the row (direction of travel, away from the dock is +X)
    Y = v  up the slope, from the lower module edge (v = 0) to the upper edge (v = mod_l)
    Z = w  normal to the glass, glass surface at w = 0, frame top at w = frame_proud
The robot is centred at u = 0. build_components() returns every made and bought component as
a Comp (name, shape, BOM line, media group); robot_parts() and dock_parts() group them the way
the calculation note and the concept media use them. The same PARAMS feed
docs/04-calcs/sizing.py (DRN-CAL-001). BUILD PLAN MODEL, PLAN NOT YET BUILT; not for fabrication.

Design for construction (DRN-DDR-003, 2026-09-30): plate gap 28 mm with clevis-mounted guide
rollers, a sprung hook slider, flange bearings, drive housings carrying the motors, beam end cleats,
hood spacers, sunshade posts, sensor and contact brackets, a robot-side latch solenoid, dock cross
members kept clear of the hook roller path, rail brackets, frame clamps, a contact post, bolted
legs, a vertical anemometer mast and three-piece end stops that sit below the IR sensors.
"""
import sys
from collections import namedtuple
from math import radians, sin, cos
from pathlib import Path

# Top-level parameters (mm, degrees). Edit these, not the geometry below.
PARAMS = {
    # reference module and table (DRN-REQ-001 reference row)
    "mod_l": 2278.0,          # module length up the slope (1P portrait)
    "mod_w": 1134.0,          # module width along the row
    "gap": 20.0,              # gap between modules along the row
    "lip": 25.0,              # frame top flange width seen from above (assumed; see DRN-CAL-001)
    "frame_d": 33.0,          # frame depth
    "frame_t": 2.5,           # frame wall (massing)
    "frame_proud": 1.0,       # frame top above the glass surface
    "tilt": 25.0,             # table tilt
    "h0": 600.0,              # lower glass edge above ground
    # chassis beam: 40 x 80 x 2 mm 6063 aluminum rectangular tube, long side normal to the glass
    "beam_b": 40.0, "beam_h": 80.0, "beam_t": 2.0,
    # microfiber brush
    "brush_d": 120.0,         # sleeve outside diameter
    "core_d": 50.0, "core_t": 2.0,   # aluminum core tube (50 mm keeps the interference in band, DRN-CAL-001 B5)
    "shaft_d": 20.0,          # stub shafts in the flange bearings (15 mm outboard of the lower bearing)
    "plug_l": 20.0,           # turned end plug inside each end of the core
    "brush_edge": 40.0,       # brushed band starts this far from each module edge
    "interference": 4.5,      # nominal pile interference at the bearings (R3: 3 to 5 mm along the sleeve)
    # hood (bent aluminum sheet over the brush, with end guards), hung from the beam on 3 mm spacers
    "hood_r": 76.0, "hood_t": 0.8, "hood_clear": 25.0,   # hood lower edges this far above the brush axis
    # end trucks
    "plate_t": 5.0,           # 5 mm aluminum plate
    "plate_half_u": 130.0,    # plate 260 mm along the row
    "plate_w": (-80.0, 216.0),  # plate extent normal to the glass (below the hook spring seat to the beam top)
    "plate_gap": 28.0,        # plate inner face this far outboard of the frame outer face (room for the guide clevises)
    "housing_d": 40.0,        # drive housing depth outboard of the plate (bearings, pulleys, belts, coupling)
    "wheel_d": 70.0, "wheel_w": 18.0,     # polyurethane wheels on the frame top flange
    "wheel_u": 90.0,          # wheel centers at +/- this along the row (wheelbase 180 mm)
    "wheel_v": (3.0, 21.0),   # wheel tread on the frame flange, from the frame outer face
    "axle_d": 10.0,           # wheel axles in two 2-bolt flange bearings each
    "guide_d": 22.0, "guide_u": 60.0,     # guide rollers on the frame outer face, each in a clevis
    "hook_d": 16.0, "hook_v": (3.0, 21.0),  # hook roller under the frame bottom flange
    "hook_axle_d": 8.0,       # hook roller axle, cantilevered from the slider
    # drives
    "drive_d": 37.0, "drive_l": 66.0,     # 37 mm gearmotor with encoder
    "brush_motor": (70.0, 66.0, 70.0),    # brush gearmotor envelope (u, v, w)
    # enclosures on the beam
    "pack": (65.0, 151.0, 94.0),          # 12.8 V 10 Ah LiFePO4 (u, v, w), common 151 x 65 x 94 mm case
    "pack_v": 250.0,                      # pack lower end from the lower module edge
    "ebox": (80.0, 140.0, 55.0),          # IP65 controller box
    "ebox_v": 480.0,
    "shade_t": 1.0,                       # sunshade over pack and controller
    "shade_gap": 6.0,                     # air gap between the pack top and the sunshade
    # dock (continues the frame profile past the row start)
    "dock_rail_l": 780.0,                 # parking rails
    "dock_u0": -1300.0,                   # far end of the dock (panel bay)
    "cross": 40.0,                        # dock cross members and legs, 40 x 40 x 2 square tube
    "cross_top": -38.0,                   # top of the dock cross members (6 mm below the frame bottom)
    "panel": (350.0, 530.0, 25.0),        # 20 W panel (u, v, w)
    "mast_h": 560.0,                      # vertical anemometer mast length
    # end stop
    "stop_l": 40.0, "stop_h": 39.0,       # stop block top 40 mm above the glass, below the IR sensors
    "buffer_t": 5.0,
}

P = PARAMS
Comp = namedtuple("Comp", "name shape bom group")


def derived(p=PARAMS):
    """Dimensions the calculation note and drawing use, computed from PARAMS."""
    d = {}
    d["glass_v"] = (p["lip"], p["mod_l"] - p["lip"])
    d["glass_across"] = p["mod_l"] - 2 * p["lip"]
    d["brush_v"] = (p["brush_edge"], p["mod_l"] - p["brush_edge"])
    d["brush_len"] = d["brush_v"][1] - d["brush_v"][0]
    d["brush_w"] = p["brush_d"] / 2 - p["interference"]       # brush axis height above the glass
    d["wheel_c"] = p["frame_proud"] + p["wheel_d"] / 2        # wheel axle height
    d["hook_c"] = p["frame_proud"] - p["frame_d"] - p["hook_d"] / 2
    d["hood_top"] = d["brush_w"] + p["hood_r"] + p["hood_t"]
    d["beam_w"] = (d["hood_top"] + 3.0, d["hood_top"] + 3.0 + p["beam_h"])
    d["plate_v"] = (-p["plate_gap"] - p["plate_t"], -p["plate_gap"])
    d["span"] = p["mod_l"] + 2 * p["plate_gap"]                # between plate inner faces
    d["beam_len"] = d["span"]
    d["housing_v"] = (d["plate_v"][0] - p["housing_d"], d["plate_v"][0])
    d["overall_v"] = p["mod_l"] + 2 * (p["plate_gap"] + p["plate_t"] + p["housing_d"] + p["drive_l"])
    d["overall_u"] = 2 * p["plate_half_u"] + 2 * 22.0        # plate plus IR sensors
    d["contact_w"] = 2 * ((p["brush_d"] / 2) ** 2 - d["brush_w"] ** 2) ** 0.5   # brush contact width on the glass
    d["shade_w"] = d["beam_w"][1] + p["pack"][2] + p["shade_gap"]
    d["top_w"] = d["shade_w"] + p["shade_t"]
    d["frame_bot"] = p["frame_proud"] - p["frame_d"]
    d["rail_u"] = (-p["gap"] - p["dock_rail_l"], -p["gap"])
    d["cross_u"] = (p["dock_u0"], d["rail_u"][0], -p["gap"] - 100.0)   # far, rail-start and near cross members (-u face)
    return d


# ---------------- helpers ----------------
def bx(u0, u1, v0, v1, w0, w1):
    from build123d import Box, Pos
    return Pos((u0 + u1) / 2, (v0 + v1) / 2, (w0 + w1) / 2) * Box(abs(u1 - u0), abs(v1 - v0), abs(w1 - w0))


def cyl_u(v, w, u0, u1, r):
    from build123d import Cylinder, Pos, Rot
    return Pos((u0 + u1) / 2, v, w) * Rot(0, 90, 0) * Cylinder(r, abs(u1 - u0))


def cyl_v(u, w, v0, v1, r):
    from build123d import Cylinder, Pos, Rot
    return Pos(u, (v0 + v1) / 2, w) * Rot(90, 0, 0) * Cylinder(r, abs(v1 - v0))


def cyl_w(u, v, w0, w1, r):
    from build123d import Cylinder, Pos
    return Pos(u, v, (w0 + w1) / 2) * Cylinder(r, abs(w1 - w0))


def ring_v(u, w, v0, v1, r_out, r_in):
    return cyl_v(u, w, v0, v1, r_out) - cyl_v(u, w, v0 - 1, v1 + 1, r_in)


def tube(a, b, r):
    from build123d import Solid, Plane, Vector
    a = Vector(*a); b = Vector(*b); d = b - a
    return Solid.make_cylinder(r, d.length, Plane(origin=a, z_dir=d.normalized()))


def fuse(shapes):
    out = None
    for s in shapes:
        if s is None:
            continue
        out = s if out is None else out + s
    return out


def mirror_v(shape, p=PARAMS):
    """Mirror a lower-end shape to the upper module edge (v -> mod_l - v)."""
    from build123d import Plane, Pos
    return Pos(0, p["mod_l"], 0) * shape.mirror(Plane.XZ)


def to_world(shape, p=PARAMS):
    """Local (u, v, w) table coordinates to world (Z up, ground at Z = 0), as in concept_media.py."""
    from build123d import Pos, Rot
    return Pos(0, 0, p["h0"]) * Rot(0, 0, 90) * Rot(p["tilt"], 0, 0) * shape


def to_local(shape, p=PARAMS):
    from build123d import Pos, Rot
    return Rot(-p["tilt"], 0, 0) * Rot(0, 0, -90) * Pos(0, 0, -p["h0"]) * shape


def local_point_to_world(u, v, w, p=PARAMS):
    t = radians(p["tilt"])
    return (-(v * cos(t) - w * sin(t)), u, p["h0"] + v * sin(t) + w * cos(t))


def frame_edge(u0, u1, p=PARAMS):
    """Module frame profile at the lower edge (C section open toward the glass): top flange,
    outer web and bottom flange. Used for the reference module and the dock rails."""
    top = p["frame_proud"]; bot = top - p["frame_d"]; t = p["frame_t"]
    return (bx(u0, u1, 0, p["lip"], top - t, top) + bx(u0, u1, 0, t, bot, top)
            + bx(u0, u1, 0, p["lip"], bot, bot + t))


def frame_end(u0, sign, p=PARAMS):
    """Module frame along a long side (u end), C section open toward the glass (+u for sign=+1)."""
    top = p["frame_proud"]; bot = top - p["frame_d"]; t = p["frame_t"]; L = p["mod_l"]
    a, b = (u0, u0 + sign * p["lip"])
    a, b = min(a, b), max(a, b)
    wa, wb = (u0, u0 + sign * t)
    wa, wb = min(wa, wb), max(wa, wb)
    return bx(a, b, 0, L, top - t, top) + bx(wa, wb, 0, L, bot, top) + bx(a, b, 0, L, bot, bot + t)


# ---------------- robot ----------------
def _truck(p, lower=True):
    """One end truck at the lower module edge (the upper truck is its mirror image); lower=True
    adds the brush drive, the dock contact bracket and the latch solenoid."""
    d = derived(p)
    pv0, pv1 = d["plate_v"]
    hv0, hv1 = d["housing_v"]
    hu = p["plate_half_u"]; wc = d["wheel_c"]; wr = p["wheel_d"] / 2; bw = d["brush_w"]
    wu = p["wheel_u"]
    c = {}
    # plate with holes for the axles, the lower brush shaft and the stop button
    plate = bx(-hu, hu, pv0, pv1, *p["plate_w"])
    for su in (-1, 1):
        plate -= cyl_v(su * wu, wc, pv0 - 1, pv1 + 1, p["axle_d"] / 2 + 1)
    if lower:
        plate -= cyl_v(0, bw, pv0 - 1, pv1 + 1, 11)
    plate -= cyl_v(95, 185, pv0 - 1, pv1 + 1, 11)
    for su in (-1, 1):
        plate -= cyl_v(su * 13, -40, pv0 - 1, pv1 + 1, 3.25)                 # hook slider shoulder bolts
        for wz in (25.0, 55.0):
            plate -= cyl_v(su * 37, d["beam_w"][0] + wz, pv0 - 1, pv1 + 1, 3.25)   # beam cleat bolts
    c["plate"] = plate
    # wheels, axles, two 2-bolt flange bearings per axle (one each side of the plate), pulleys and belt
    wheels = axles = bearings = pulleys = None
    for su in (-1, 1):
        u = su * wu
        wheels = fuse([wheels, ring_v(u, wc, *p["wheel_v"], wr, p["axle_d"] / 2)])
        axles = fuse([axles, cyl_v(u, wc, hv0 + 16, p["wheel_v"][1], p["axle_d"] / 2)])
        for v0, v1, h0, h1 in ((pv1, pv1 + 7, pv1 + 7, pv1 + 12), (pv0 - 7, pv0, pv0 - 12, pv0 - 7)):
            bearings = fuse([bearings, bx(u - 18, u + 18, v0, v1, wc - 30, wc + 30) - cyl_v(u, wc, v0 - 1, v1 + 1, p["axle_d"] / 2),
                             ring_v(u, wc, h0, h1, 14, p["axle_d"] / 2)])
        pulleys = fuse([pulleys, ring_v(u, wc, hv0 + 16, hv0 + 26, 8, p["axle_d"] / 2)])
    belt = (bx(-wu, wu, hv0 + 16.5, hv0 + 25.5, wc - 9.5, wc + 9.5) + cyl_v(-wu, wc, hv0 + 16.5, hv0 + 25.5, 9.5)
            + cyl_v(wu, wc, hv0 + 16.5, hv0 + 25.5, 9.5)) - (bx(-wu, wu, hv0 + 16, hv0 + 26, wc - 8, wc + 8)
                                                           + cyl_v(-wu, wc, hv0 + 16, hv0 + 26, 8) + cyl_v(wu, wc, hv0 + 16, hv0 + 26, 8))
    c["wheels"] = wheels
    c["axles"] = axles + pulleys + belt
    c["axle_bearings"] = bearings
    # coupling from the drive motor shaft to the +u axle, inside the housing
    c["coupling"] = cyl_v(wu, wc, hv0 + 3, hv0 + 15, 8)
    # drive housing: 3 mm folded tray screwed to the plate's outer face by side flanges; the motors bolt to its outer wall
    htop = 160.0 if lower else 74.0
    hb = -5.0
    ht = 2.0 if lower else 1.5                                               # 2 mm sheet where the brush motor hangs
    housing = bx(-118, 118, hv0, pv0, hb, htop) - bx(-118 + ht, 118 - ht, hv0 + ht, pv0 + 1, hb + ht, htop - ht)
    housing -= cyl_v(wu, wc, hv0 - 1, hv0 + 4, 4)                           # motor shaft hole
    if lower:
        housing -= cyl_v(0, 117, hv0 - 1, hv0 + 4, 5)                      # brush motor shaft hole
    flanges = bx(118, 130, pv0 - 3, pv0, hb, htop) + bx(-130, -118, pv0 - 3, pv0, hb, htop)
    c["housing"] = housing + flanges
    # drive gearmotor, face-mounted on the housing's outer wall, coaxial with the +u axle
    c["drive_motor"] = cyl_v(wu, wc, hv0 - p["drive_l"], hv0, p["drive_d"] / 2) + cyl_v(wu, wc, hv0, hv0 + 4, 3)
    # guide rollers, each on an M8 bolt in a folded 3 mm clevis screwed to the plate's inner face
    gr = p["guide_d"] / 2
    guides = clevis = None
    for su in (-1, 1):
        u = su * p["guide_u"]
        guides = fuse([guides, cyl_w(u, -gr, -27, -4, gr) - cyl_w(u, -gr, -28, -3, 4)])
        clevis = fuse([clevis, bx(u - 11, u + 11, pv1, pv1 + 3, -30, -1), bx(u - 11, u + 11, pv1 + 3, -5, -30, -27),
                       bx(u - 11, u + 11, pv1 + 3, -5, -4, -1)]) - cyl_w(u, -gr, -31, 0, 4.25)
    c["guide_rollers"] = guides
    c["guide_clevises"] = clevis
    # hook roller on an 8 mm axle cantilevered from a 10 mm slider; slider rides on two shoulder bolts
    # in the plate and is pushed up by a compression spring on a seat bracket (70 N preload)
    hc = d["hook_c"]; hr = p["hook_d"] / 2
    c["hook_roller"] = ring_v(0, hc, *p["hook_v"], hr, p["hook_axle_d"] / 2)
    c["hook_axle"] = cyl_v(0, hc, pv1 + 10, p["hook_v"][1] + 2, p["hook_axle_d"] / 2)
    c["hook_slider"] = (bx(-20, 20, pv1, pv1 + 10, -55, -25) - cyl_v(0, hc, pv1 - 1, pv1 + 11, p["hook_axle_d"] / 2)
                        - bx(-16.25, -9.75, pv1 - 1, pv1 + 11, -47, -33) - bx(9.75, 16.25, pv1 - 1, pv1 + 11, -47, -33))
    c["hook_spring"] = cyl_w(0, pv1 + 5, -75, -55, 4.5) - cyl_w(0, pv1 + 5, -76, -54, 3)
    c["spring_seat"] = bx(-15, 15, pv1, pv1 + 3, -80, -62) + bx(-15, 15, pv1 + 3, pv1 + 12, -78, -75)
    # brush flange bearing on the plate's inner face (both trucks)
    c["brush_bearing"] = (bx(-30, 30, pv1, pv1 + 8, bw - 45, bw + 45) + cyl_v(0, bw, pv1 + 8, pv1 + 22, 20)
                          - cyl_v(0, bw, pv1 - 1, pv1 + 23, p["shaft_d"] / 2))
    # beam end cleats: 40 x 40 x 4 angle each side of the beam, through-bolted across it and bolted to the plate
    bw0, bw1 = d["beam_w"]
    b2 = p["beam_b"] / 2
    cl = None
    for su in (-1, 1):
        a0, a1 = sorted((su * b2, su * (b2 + 3)))
        c0, c1 = sorted((su * b2, su * (b2 + 30)))
        cl = fuse([cl, bx(a0, a1, pv1 + 3, pv1 + 30, bw0 + 5, bw0 + 75), bx(c0, c1, pv1, pv1 + 3, bw0 + 5, bw0 + 75)])
    holes = (cyl_u(pv1 + 17, bw0 + 25, -b2 - 10, b2 + 10, 3.25) + cyl_u(pv1 + 17, bw0 + 55, -b2 - 10, b2 + 10, 3.25)
             + fuse([cyl_v(su * 37, bw0 + wz, pv1 - 1, pv1 + 4, 3.25) for su in (-1, 1) for wz in (25.0, 55.0)]))
    c["cleats"] = cl - holes
    c["beam_holes"] = cyl_u(pv1 + 17, bw0 + 25, -b2 - 1, b2 + 1, 3.25) + cyl_u(pv1 + 17, bw0 + 55, -b2 - 1, b2 + 1, 3.25)
    c["cleat_bolts"] = (cyl_u(pv1 + 17, bw0 + 25, -b2 - 9, b2 + 9, 3) + cyl_u(pv1 + 17, bw0 + 55, -b2 - 9, b2 + 9, 3)
                        + cyl_v(37, bw0 + 25, pv0 - 4, pv1 + 4, 3) + cyl_v(-37, bw0 + 25, pv0 - 4, pv1 + 4, 3)
                        + cyl_v(37, bw0 + 55, pv0 - 4, pv1 + 4, 3) + cyl_v(-37, bw0 + 55, pv0 - 4, pv1 + 4, 3))
    # IR edge sensors, two per truck, on folded 3 mm brackets screwed to the plate's inner face
    sens = brk = None
    for su in (-1, 1):
        s0, s1 = sorted((su * hu, su * (hu + 22)))
        k0, k1 = sorted((su * 112, su * 130))
        h0, h1 = sorted((su * 112, su * (hu + 22)))
        sens = fuse([sens, bx(s0, s1, p["wheel_v"][0], p["wheel_v"][1], 45, 78)])
        brk = fuse([brk, bx(k0, k1, pv1, pv1 + 3, 55, 78), bx(h0, h1, pv1, p["wheel_v"][1], 78, 81)])
    c["sensors"] = sens
    c["sensor_brackets"] = brk
    # emergency stop button through a 22 mm hole in the plate
    c["estop"] = cyl_v(95, 185, pv0 - 40, pv0, 20) + cyl_v(95, 185, pv1, pv1 + 30, 15)
    if lower:
        # brush stub shaft, flange bearing outboard side, pulleys, belt and brush gearmotor
        mu, mv, mw = p["brush_motor"]
        mz = 117.0
        c["brush_pulleys"] = (ring_v(0, bw, hv0 + 4, hv0 + 14, 12, 7.5) + ring_v(0, mz, hv0 + 4, hv0 + 14, 12, 3))
        c["brush_belt"] = ((bx(-13.5, 13.5, hv0 + 4.5, hv0 + 13.5, bw, mz) + cyl_v(0, bw, hv0 + 4.5, hv0 + 13.5, 13.5)
                            + cyl_v(0, mz, hv0 + 4.5, hv0 + 13.5, 13.5))
                           - (bx(-12, 12, hv0 + 4, hv0 + 14, bw, mz) + cyl_v(0, bw, hv0 + 4, hv0 + 14, 12) + cyl_v(0, mz, hv0 + 4, hv0 + 14, 12)))
        c["brush_motor"] = bx(-mu / 2, mu / 2, hv0 - mv, hv0, mz - mw / 2, mz + mw / 2) + cyl_v(0, mz, hv0, hv0 + 14, 3)
        # robot-side dock contacts: insulating block with three copper strips on a folded bracket,
        # and the latch: a 12 V pull solenoid whose spring-out 6 mm pin drops into the dock latch tab
        c["contact_bracket"] = (bx(-127, -100, pv1, pv1 + 3, 88, 150) + bx(-130, -127, pv1, 18, 88, 126)
                                + bx(-127, -100, pv1 + 3, 5, 147, 150)) - cyl_w(-115, -8, 146, 151, 3.5)
        c["contact_pad"] = bx(-138, -130, pv1 + 1, 18, 90, 126)
        c["solenoid"] = cyl_w(-115, -8, 150, 180, 12) + cyl_w(-115, -8, 124, 150, 3)
    return c


def _brush_and_hood(p):
    d = derived(p)
    pv0, pv1 = d["plate_v"]; hv0 = d["housing_v"][0]
    L = p["mod_l"]; bw = d["brush_w"]; v0, v1 = d["brush_v"]
    rc = p["core_d"] / 2; ri = rc - p["core_t"]
    c = {}
    c["sleeve"] = ring_v(0, bw, v0, v1, p["brush_d"] / 2, rc)
    c["core"] = ring_v(0, bw, v0 - 10, v1 + 10, rc, ri)
    c["plugs"] = (ring_v(0, bw, v0 - 10, v0 - 10 + p["plug_l"], ri, p["shaft_d"] / 2)
                  + ring_v(0, bw, v1 + 10 - p["plug_l"], v1 + 10, ri, p["shaft_d"] / 2))
    lower = cyl_v(0, bw, pv0, v0 - 10 + p["plug_l"], p["shaft_d"] / 2) + cyl_v(0, bw, hv0 + 3, pv0, 7.5)
    upper = cyl_v(0, bw, v1 + 10 - p["plug_l"], L - pv1 - 2, p["shaft_d"] / 2)
    c["shafts"] = lower + upper
    # hood: part of a ring above the brush, with end guards
    r0, r1 = p["hood_r"], p["hood_r"] + p["hood_t"]
    ring = ring_v(0, bw, v0 - 5, v1 + 5, r1, r0)
    hood = ring & bx(-r1 - 1, r1 + 1, v0 - 6, v1 + 6, bw + p["hood_clear"], bw + r1 + 1)
    guard = (cyl_v(0, bw, v0 - 6, v0 - 5, r1) & bx(-r1, r1, v0 - 7, v0 - 4, bw + p["hood_clear"], bw + r1))
    c["hood"] = hood + guard + mirror_v(guard, p)
    # sunshade over pack and controller, on four 12 mm spacer posts screwed into the beam's top wall
    bw1 = d["beam_w"][1]; sw = d["shade_w"]
    sv0, sv1 = p["pack_v"] - 20, p["ebox_v"] + p["ebox"][1] + 20
    c["shade"] = bx(-60, 60, sv0, sv1, sw, sw + p["shade_t"])
    c["shade_posts"] = fuse([cyl_w(su * 12, vv, bw1, sw, 6) - cyl_w(su * 12, vv, bw1 - 1, sw + 1, 3)
                             for su in (-1, 1) for vv in (sv0 + 8, sv1 - 8)])
    # hood spacers: 3 mm nylon spacers on M5 screws into rivet nuts in the beam's lower wall
    hs = d["hood_top"]
    c["hood_spacers"] = fuse([cyl_w(0, vv, hs, d["beam_w"][0], 6) for vv in (300.0, 760.0, L / 2, L - 760.0, L - 300.0)])
    return c
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

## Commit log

2026-09-24 Initial scaffold: standard open hardware layout, CERN-OHL-S v2 + MIT licenses
    Claude-Session: https://claude.ai/code/session_01XuhhSU4W6fYhgCfURbrkut
    [bom.csv]
2026-09-25 Adopt portfolio kit v1.3.0: session commands, scale figure, 3D viewer, flow diagrams
    Adds .claude/commands (/populate, /advance-trl3, /rein-in, /refresh-media)
    so every Claude Code session starts from the standard prompts, and extends
    concept media with a 1.75 m scale figure, an interactive glTF viewer and
    system or energy flow diagrams. TRL cap 3 unchanged.
    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
2026-09-25 Kit v1.3.1: renderer fixes from the TremorTrace pilot
    Context scale parts for small objects, cutaway exclusions, and text
    labels in flow diagrams.
    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
2026-09-25 Populate dustrunner to a strong TRL 2 with concept media (overnight batches 4 and 5)
    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
    [bom.csv]
2026-09-25 Advance dustrunner to TRL 3 (batch 4)
    Decisions approved by Amish 2026-09-25 recorded in DDR-001. TRL 4 is on hold.
    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
    [bom.csv, dustrunner-assembly.step, dustrunner-dock.step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]
2026-09-26 Accept all recommendations (DDR-002), switch footer to designmolecule.com, add README write-up with new inspiration point
    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
    [dustrunner-assembly.step, dustrunner-dock.step, dustrunner-end-stop.step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]
2026-09-27 Product appearance model and photoreal renders
    Adds cad/src/product_model.py (appearance model for renders only, all main
    dimensions from model.py) and Blender renders in media/render-*.png,
    captioned with the project, repository and viewing direction. README leads
    with the product render; trl stays 3.
    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
2026-10-01 Image quality pass: legible exploded views, flow diagrams and drawing sheets
    Kit 1.6.1 image layout: the parts list sits in its own column, number bubbles sit on visible parts and never overlap, small parts get a leader, pictures are cropped to the subject, flow labels keep numbers with their units, and sheet captions and the revision table no longer overprint. Concept images, blueprint and general arrangement sheet regenerated; repo-specific labels moved clear of other text and lines.
2026-10-01 Kit 1.7.0: constructable design, illustrated build plan and design decisions register
    The design is now constructable: every part can be made and fits its neighbours, with each change recorded in a Design for construction decision record (made under Amish's 2026-09-30 instruction; ope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
    [bom.csv, dustrunner-assembly.step, dustrunner-dock.step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]
2026-10-02 Record Amish's approval of the open-decision recommendations
    Amish approved the recommendation on every open decision in the design decisions register ("i approve your recommendations for all 555 open decisions.", 2026-10-02). Each decision is moved to Decisio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
2026-10-03 Carry approved follow-ups into the design and redo photoreal renders
    Amish approved the follow-up actions from the open-decision sign-off ("APPROVED CHANGES, COMPLETE THESE", 2026-10-02), the design-for-construction change tables in ten repos, the last wave's open dec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

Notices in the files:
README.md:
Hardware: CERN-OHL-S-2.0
